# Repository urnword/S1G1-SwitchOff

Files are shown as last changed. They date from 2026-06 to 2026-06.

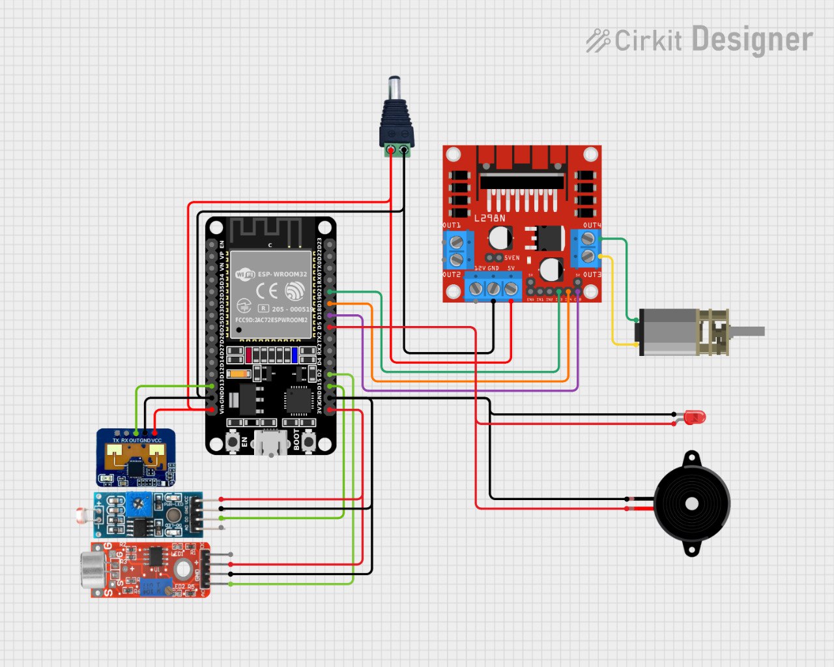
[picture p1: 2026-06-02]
hardware/circuit_diagram.jpg

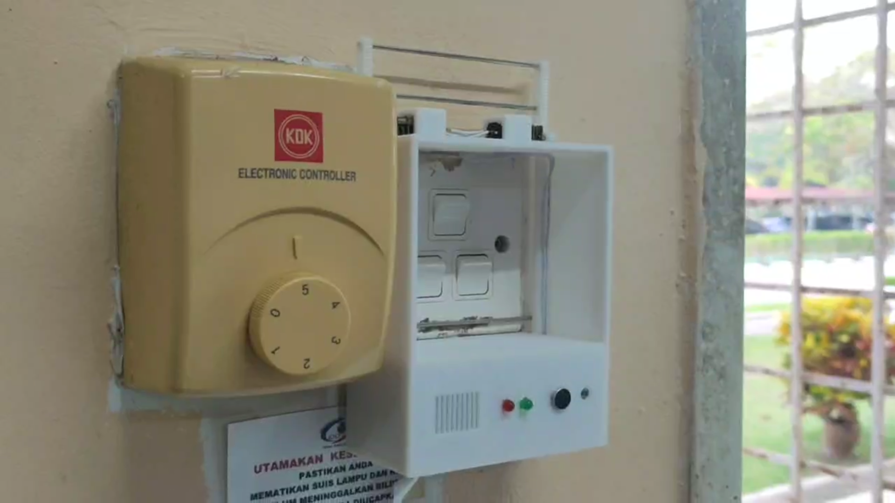
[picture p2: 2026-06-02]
docs/media/prototype.png

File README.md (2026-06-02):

# 💡 Switch Off!!!

> An IoT-powered smart switch actuator that automatically turns off lights and fans when you leave the room — controlled remotely via a web dashboard.

**CT115/CT125 Digital Technology · Semester I/II 2025/2026 · TECH CC SDN BHD**


[]()
[]()
[]()
[]()

---

## 🎯 Problem Statement

Students in dormitories routinely leave lights and fans running after leaving their rooms, leading to unnecessary energy waste, higher utility bills, and increased carbon emissions. Existing smart switch solutions require electrical rewiring — not feasible in a rented dorm environment.

## 💡 Our Solution

**Switch Off!!!** is a plug-and-play device that mounts **over** an existing wall switch without any electrical modification. It uses a motorised rack-and-pinion mechanism to physically flip the switch, controlled by an ESP32 microcontroller connected to Firebase via Wi-Fi.

Users can:
- **Monitor** room status (presence, light, fan) in real time via a web dashboard
- **Control** switches remotely from anywhere
- **Automate** switch-off when no human presence is detected for a set duration

---

## 🌐 Live Demo

👉 **[https://studio--switch-off-b68c4.us-central1.hosted.app/](https://studio--switch-off-b68c4.us-central1.hosted.app/)**

> MVP build — core monitoring and manual control features are live.

---

## 📁 Repository Structure

```
switch-off/
├── README.md                  ← You are here
├── firmware/
│   ├── README.md              ← Firmware setup & flashing guide
│   └── main.py                ← MicroPython source (ESP32)
├── hardware/
│   ├── README.md              ← Hardware assembly guide
│   ├── circuit_diagram.png    ← Wiring diagram (Cirkit Designer)
│   └── bom.md                 ← Bill of Materials
├── docs/
│   ├── README.md              ← Full project documentation
│   ├── report.pdf             ← Official project report
│   └── media/
│       ├── dashboard.png      ← Web dashboard screenshots
│       ├── prototype.jpg      ← Physical prototype photos
│       └── demo.mp4           ← Demo video
```

---

## 🔧 Hardware Overview

| Component | Role |
|---|---|
| ESP32 NodeMCU (ESP32S) | Main microcontroller — Wi-Fi, logic, motor control |
| GA12-N20 Geared Motor (3V 15RPM) | Physical switch actuation |
| L298N Mini Motor Driver | Motor direction & speed control |
| HLK-LD2410C mmWave Sensor | Human presence detection (motion + stationary) |
| GL55 LDR Sensor | Light level detection (switch ON/OFF status) |
| KY-037 Sound Sensor | Fan vibration/noise detection |
| Rack & Pinion + Metal Shaft | Converts motor rotation → linear switch movement |
| 5V 3A DC Adapter | System power supply |

> See [`hardware/README.md`](hardware/README.md) for full assembly instructions and [`hardware/bom.md`](hardware/bom.md) for sourcing details.

---

## 🖥️ Software Stack

| Layer | Technology |
|---|---|
| Firmware | MicroPython on ESP32 |
| Cloud / Database | Firebase Firestore |
| Web Dashboard | Next.js hosted on Firebase Hosting |
| 3D Enclosure Design | FreeCAD 1.0 |
| Circuit Design | Cirkit Designer |

---

## ⚡ How It Works

```
┌─────────────┐     Wi-Fi / Firestore       ┌──────────────────┐
│   ESP32     │ ◄─────────────────────────► │  Firebase Cloud  │
│             │                             └────────┬─────────┘
│  Sensors:   │                                      │ Real-time sync
│  • mmWave   │                             ┌────────▼─────────┐
│  • LDR      │                             │   Next.js Web    │
│  • Sound    │                             │   Dashboard      │
│             │                             │  (User Control)  │
│  Actuator:  │                             └──────────────────┘
│  • N20 Motor│
│  • L298N    │
└─────────────┘
       │
       ▼ Physical rack & pinion
  ┌─────────┐
  │  Wall   │
  │ Switch  │ ← flipped ON / OFF
  └─────────┘
```

**Auto-Off Logic:**
1. mmWave sensor continuously checks for human presence
2. If no presence detected + light/fan still ON → starts countdown timer
3. After delay threshold → motor activates to flip the switch OFF
4. Status synced to dashboard in real time

---

## 🚀 Getting Started

### Prerequisites
- ESP32 board (ESP32S / NodeMCU)
- MicroPython firmware flashed on the board
- Firebase project (Firestore enabled)
- Node.js 18+ (for web dashboard)

### 1. Flash the Firmware
See [`firmware/README.md`](firmware/README.md) for full flashing and configuration steps.

### 2. Configure Firebase
Update your Firestore credentials and device URL in `firmware/main.py`:
```python
WIFI_SSID = "your_wifi"
WIFI_PASS = "your_password"
DEVICE_URL = "your_firestore_device_url"
```

### 3. Run the Web Dashboard
```bash
cd web
npm install
npm run dev
```
Or deploy to Firebase Hosting — see [`docs/README.md`](docs/README.md).

---

## 📊 Test Results

| Test | Description | Result |
|---|---|---|
| TC-01 Unit | mmWave range detection (1m–5m) | ✅ Pass |
| TC-02 Unit | Sound sensor fan vs. speech isolation | ✅ Pass (after tuning) |
| TC-03 System | Environmental adaptability across rooms | ✅ Pass |
| TC-04 Integration | Data latency under rapid toggle | ✅ Pass (minor ms delay) |
| TC-05 Acceptance | Live subject real-world test ("Bilik Felo") | ✅ Pass |

Status accuracy after sensor calibration: **>90%**

---

## ⚠️ Known Limitations

- Requires constant plug-in power (no battery option yet)
- Multi-switch panels toggle all switches simultaneously (no individual control yet)
- Performance depends on Wi-Fi signal strength
- Regulator-style switches (positioned above the switch) are not currently supported

---

## 🔮 Future Work

- Support for a wider variety of switch types and configurations
- Individual switch control in multi-switch panels
- Battery / USB-C power option for portability
- User-friendly instruction manual with debugging guide
- Scheduling and energy usage analytics in the app

---

## 👥 Team — TECH CC SDN BHD

**TAIB HAZMI BIN TAIBRIZAL** • *Project Lead*

**MUHAMMAD ALTAMIS ZAFRAN BIN MOHD AFFENDY** • *Hardware Developer*

**MUHAMAD ZAID IZZUDDIN BIN NAZRI** • *Software Developer*

**NUR ERNA NADIRAH BINTI AMINUDDIN** • *System Designer*

---

## 📚 References

- Alam, M. R. et al. (2020). A review of smart homes — Past, present, and future. *Energies, 13*(15). https://doi.org/10.3390/en13154035
- Random Nerd Tutorials. ESP32 with DC motor and L298N motor driver. https://www.youtube.com/watch?v=E2sTbpFsvXI
- ESP32IO. ESP32 - Photoresistor (GL55 series) tutorial. https://esp32io.com/

---

## 📄 License

This project was developed as an academic submission for CT115/CT125 Digital Technology, Bahagian Matrikulasi, Kementerian Pendidikan Malaysia. 

© 2026 TECH CC SDN BHD. All rights reserved.

The source code and design files in this repository are provided solely for educational review and portfolio demonstration purposes. Permission is granted to view the materials, but cloning, modifying, or redistributing this work for commercial use or academic re-submission under a different name is strictly prohibited.

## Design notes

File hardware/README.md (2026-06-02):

# 🔩 Hardware — Switch Off!!!

Assembly guide, wiring reference, and Bill of Materials for the Switch Off!!! smart switch actuator.

---

## 📁 Files

```
hardware/
├── README.md           ← This file (assembly guide)
├── circuit_diagram.png ← Full wiring diagram (Cirkit Designer)
├── enclosure.stl       ← Product 3d model ensclosure
└── bom.md              ← Bill of Materials with sourcing notes
```

---

## 🧩 Bill of Materials (Quick Reference)

| # | Component | Spec | Qty |
|---|---|---|---|
| 1 | ESP32 NodeMCU (ESP32S) | 38-pin, built-in Wi-Fi/BT | 1 |
| 2 | GA12-N20 Geared DC Motor | 3V, 15RPM | 1–4 |
| 3 | L298N Mini Motor Driver | Dual H-bridge | 1 |
| 4 | HLK-LD2410C mmWave Sensor | 24GHz FMCW radar | 1 |
| 5 | GL55 LDR Module | Light-dependent resistor | 1 |
| 6 | KY-037 Sound Sensor | Microphone + comparator | 1 |
| 7 | Rack & Pinion set | Plastic, compatible with N20 shaft | 1 |
| 8 | Metal shaft | 2mm diameter | 1 |
| 9 | 5V 3A DC Power Adapter | Regulated DC | 1 |
| 10 | DC Barrel Connector (female) | 5.5mm × 2.1mm | 1 |
| 11 | LED (red + green) | 5mm, with 220Ω resistors | 2 |
| 12 | Buzzer | 5V passive/active | 1 |
| 13 | Jumper wires | M-M and M-F assorted | — |
| 14 | Custom 3D-printed enclosure | Designed in FreeCAD 1.0 | 1 |

> Full sourcing details and approximate costs: see [`bom.md`](bom.md)

---

## 📐 Circuit Overview

The ESP32 sits at the centre of the circuit:

- **Inputs:** mmWave sensor (UART), LDR (ADC), Sound sensor (ADC)
- **Outputs:** L298N motor driver → N20 motor, LED indicators, Buzzer
- **Power:** 5V 3A adapter → DC connector → L298N onboard 5V regulator → ESP32 + sensors

See `circuit_diagram.png` in this folder for the full wiring diagram.

---

## 🔌 Wiring Guide

### Power Rails
```
5V Adapter (+) ──► DC Connector (+) ──► L298N 12V pin (works with 5V)
                                    └──► ESP32 VIN
GND ─────────────────────────────────── All component GNDs (common ground)
```

### Motor Driver (L298N) → ESP32
```
L298N IN1  ──► ESP32 GPIO 26
L298N IN2  ──► ESP32 GPIO 27
L298N OUT1 ──► N20 Motor terminal A
L298N OUT2 ──► N20 Motor terminal B
```

### Sensors → ESP32
```
HLK-LD2410C TX  ──► ESP32 GPIO 16 (RX2)
HLK-LD2410C RX  ──► ESP32 GPIO 17 (TX2)
HLK-LD2410C VCC ──► 3.3V
HLK-LD2410C GND ──► GND

GL55 LDR AO  ──► ESP32 GPIO 35 (ADC)
GL55 LDR VCC ──► 3.3V
GL55 LDR GND ──► GND

KY-037 AO  ──► ESP32 GPIO 34 (ADC)
KY-037 VCC ──► 3.3V
KY-037 GND ──► GND
```

### Indicators
```
LED (Red)   (+) ──► 220Ω ──► ESP32 GPIO 22
LED (Green) (+) ──► 220Ω ──► ESP32 GPIO 23
Buzzer (+)       ──────────► ESP32 GPIO 21
All (-) ─────────────────────────────── GND
```

---

## 🏗️ Physical Assembly

### Enclosure & Mount

The enclosure is 3D-printed using FreeCAD 1.0. The design:
- Mounts **around** the existing wall switch panel using a custom bracket
- Holds the N20 motor aligned with the switch toggle
- Has cable routing channels for clean wire management
- Attaches without screws into the wall (adhesive or clip-based)

> ⚠️ **Important:** This design works with standard toggle switches. Regulator-style (rotary) switches positioned above or beside the toggle are not currently supported.

### Rack & Pinion Mechanism

```
N20 Motor shaft
      │
      ▼
  [Pinion gear]  ←──rotates──►  [Rack gear (linear)]
                                        │
                                        ▼
                                  Metal shaft (2mm)
                                        │
                                        ▼
                                  Switch toggle
                                  (physical contact)
```

Motor rotates → pinion drives rack → rack pushes shaft → shaft flips switch.

**Critical:** Motor run time must be calibrated (450–500ms) to avoid the shaft hitting the housing. See firmware `MOTOR_RUN_TIME_MS`.

---

## ✅ Assembly Checklist

- [ ] Solder all header pins on ESP32 and L298N
- [ ] Wire all sensor connections with common GND
- [ ] Test motor direction (forward = switch ON, backward = switch OFF)
- [ ] Print and fit enclosure — verify rack alignment with switch toggle
- [ ] Attach LDR module facing toward the light indicator of the switch/bulb
- [ ] Mount KY-037 sound sensor facing toward the fan (ceiling or wall-mounted)
- [ ] Connect 5V adapter and verify ESP32 boots (LED blink / serial output)
- [ ] Flash firmware and confirm Wi-Fi + Firestore connection

---

## ⚠️ Safety Notes

- This device operates at **5V DC only** — it does not connect to mains wiring
- Do not expose the circuit to moisture
- Ensure the motor bracket is firmly fixed before sustained use — mechanical stress can loosen the mount over time
- The device draws up to ~3A under motor load; use a rated 5V 3A adapter

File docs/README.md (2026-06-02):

# 📖 Documentation — Switch Off!!!

Full project documentation, architecture details, and deployment guide.

---

## 📁 Contents

```
docs/
├── README.md       ← This file
├── report.pdf      ← Official project report
└── media/
    ├── dashboard.png      ← Web dashboard screenshot
    ├── prototype.jpg      ← Physical prototype photos
    ├── circuit_diagram.png
    └── demo.mp4           ← Presentation video
```

---

## 🏗️ System Architecture

```
┌─────────────────────────────────────────────────────────────┐
│                         USER LAYER                          │
│                  Next.js Web Dashboard                      │
│         (Real-time monitoring + manual control)             │
└─────────────────────────┬───────────────────────────────────┘
                          │ HTTPS / Firestore SDK
┌─────────────────────────▼───────────────────────────────────┐
│                       CLOUD LAYER                           │
│                  Google Firebase                            │
│         Firestore (device state, commands, config)          │
│         Firebase Hosting (web app)                          │
└─────────────────────────┬───────────────────────────────────┘
                          │ HTTP REST (urequests)
┌─────────────────────────▼───────────────────────────────────┐
│                      DEVICE LAYER                           │
│              ESP32 NodeMCU (MicroPython)                    │
│                                                             │
│  Inputs:                        Outputs:                    │
│  • HLK-LD2410C (mmWave)         • L298N → N20 Motor        │
│  • GL55 LDR (light)             • LED indicators           │
│  • KY-037 Sound (fan)           • Buzzer                   │
└─────────────────────────────────────────────────────────────┘
                          │ Physical
┌─────────────────────────▼───────────────────────────────────┐
│                    PHYSICAL LAYER                           │
│         Rack & Pinion → Metal Shaft → Wall Switch          │
└─────────────────────────────────────────────────────────────┘
```

---

## 🔄 System Flowchart

### Main Loop (ESP32)

```
START
  │
  ▼
Initialize: Wi-Fi connect, sensor calibration
  │
  ▼
┌─────────────────────┐
│   READ SENSOR DATA  │ ◄────────────────────────┐
└────────┬────────────┘                           │
         │                                        │
         ▼                                        │
   HUMAN DETECTED?                                │
   YES ──► Motor OFF, keep devices on             │
   NO  ──► Check: LIGHT or FAN ON?                │
              YES ──► Start auto-off timer         │
                      Timer expired? ──► Motor ON │
              NO  ──► All good, no action          │
         │                                        │
         ▼                                        │
   CHECK CLOUD COMMANDS                           │
   (runMotor, config changes)                     │
         │                                        │
         ▼                                        │
   SEND STATUS TO FIRESTORE ─────────────────────┘
   (only on state change)
```

### Data Flow (Cloud)

```
ESP32 ──PATCH──► Firestore (status update)
                      │
                      ▼ real-time listener
              Next.js Dashboard (display)

User clicks "Turn Off"
       │
       ▼
Next.js ──WRITE──► Firestore (command: runMotor=true)
                        │
                        ▼ ESP32 polls every 200ms
                   ESP32 reads command ──► activates motor
                   ESP32 marks command executed=true
```

---

## 🌐 Web Dashboard

**Live:** [https://studio--switch-off-b68c4.us-central1.hosted.app/](https://studio--switch-off-b68c4.us-central1.hosted.app/)

### Features
- **Device overview** — list of registered Switch Off!!! devices
- **Real-time status** — Presence / Light / Fan / Switch state updated live
- **Manual control** — Turn On / Turn Off buttons send commands to the device
- **Device configuration** — Toggle Auto-Off, set delay duration
- **Last seen timestamp** — Know when the device last checked in

### Local Development

```bash
# Clone repo
git clone https://github.com/urnword/switch-off.git
cd switch-off/web

# Install dependencies
npm install

# Add your Firebase config
cp .env.example .env.local
# Fill in your Firebase project credentials in .env.local

# Run dev server
npm run dev
# Open http://localhost:3000
```

### Firebase Setup

1. Create a Firebase project at [console.firebase.google.com](https://console.firebase.google.com)
2. Enable **Firestore Database** (start in test mode for development)
3. Enable **Firebase Hosting**
4. Copy your Firebase config into `.env.local`

**Firestore Document Structure:**
```
devices/
  {deviceId}/
    fields:
      status:
        humanPresent: boolean
        fanOn: boolean
        lightOn: boolean
        motorState: "active" | "idle"
      config:
        autoOffEnabled: boolean
        autoOffDelayMs: number
        sensorSoundThreshold: number
        sensorLightThreshold: number
      command:
        runMotor: boolean
        direction: "forward" | "backward"
        executed: boolean
      lastSeen: timestamp
```

### Deploy to Firebase Hosting

```bash
npm run build
npx firebase deploy --only hosting
```

---

## 🧪 Testing Summary

We used a four-stage bottom-up testing framework:

### Stage 1 — Unit Testing
Each sensor tested in isolation before integration.
- mmWave calibrated for ideal detection distance (~1–3m for dorm rooms)
- Sound sensor frequency filter tuned to isolate fan hum from speech

### Stage 2 — System Testing
Weekly testing across multiple rooms to measure:
- Sensor accuracy under varying light conditions
- Motor reliability over repeated actuations

### Stage 3 — Integration Testing
Focus on cloud communication:
- Rapid toggle stress test (5 minutes continuous)
- Confirmed sub-second latency for control commands
- Server stability verified under high-frequency Firestore writes

### Stage 4 — Acceptance Testing
Real-world deployment in "Bilik Felo":
- Live test subject enters/exits room
- System correctly automated switch-off
- Physical mounting held firm on real wall switch

**Overall status accuracy: >90%** after sensor calibration.

---

## 🐛 Known Issues & Bugs Fixed

| Bug | Root Cause | Fix Applied |
|---|---|---|
| Motor "bangs" into housing | `delay()` too imprecise | Replaced with `MOTOR_RUN_TIME_MS` calibrated to 450–500ms |
| Fan status always "ON" | KY-037 picking up ambient noise | Added frequency-pattern filter in firmware |
| Device mounts poorly on multi-switch panels | Non-standard switch layouts | Redesigned bracket with adjustable mounting points |
| Presence false positives | mmWave too sensitive | Tuned detection sensitivity via UART configuration |

---

## 📚 Full References

- Alam, M. R., Reaz, M. B. I., & Ali, M. A. M. (2020). A review of smart homes — Past, present, and future. *Energies, 13*(15), 4035. https://doi.org/10.3390/en13154035
- Electronoobs. (2021). How to solder - 8 golden rules. https://www.youtube.com/watch?v=yKAJs2UZB6E
- ESP32IO. (n.d.). ESP32 tutorial. https://esp32io.com/
- ESP32IO. (2021). ESP32 - Photoresistor (GL55 series) tutorial. https://www.youtube.com/watch?v=5Aq_5n3zhaM
- Popular Science. (2015). Soldering basics. https://youtu.be/-THJq9LdazE
- Random Nerd Tutorials. (2019). ESP32 with DC motor and L298N motor driver. https://www.youtube.com/watch?v=E2sTbpFsvXI
- Zailani, N. F. B., & Othman, N. Z. B. (2024). *Getting started with Arduino and ESP32: A beginner's guide with Wokwi.* Politeknik Mersing. eISBN 978-967-2904-75-5

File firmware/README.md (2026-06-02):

# ⚙️ Firmware — Switch Off!!!

MicroPython firmware for the ESP32 NodeMCU that drives the Switch Off!!! smart switch actuator.

---

## 📋 Prerequisites

- ESP32 board (ESP32S / NodeMCU recommended)
- [MicroPython firmware](https://micropython.org/download/esp32/) flashed on the board
- [Thonny IDE](https://thonny.org/) **or** `mpremote` / `ampy` for uploading files
- Firebase Firestore project with a device document set up
- Wi-Fi network (2.4GHz)

---

## 📁 Files

```
firmware/
├── README.md       ← This file
└── main.py         ← Main firmware (runs automatically on boot)
```

---

## 🔌 Pin Mapping

| ESP32 GPIO | Connected To |
|---|---|
| GPIO 26 | L298N IN1 (Motor forward) |
| GPIO 27 | L298N IN2 (Motor backward) |
| GPIO 34 | KY-037 Sound Sensor (ADC) |
| GPIO 35 | GL55 LDR Sensor (ADC) |
| GPIO 16 (RX2) | HLK-LD2410C mmWave TX |
| GPIO 17 (TX2) | HLK-LD2410C mmWave RX |

> Adjust GPIO numbers in `main.py` if your wiring differs.

---

## ⚡ Setup & Flashing

### Step 1 — Flash MicroPython to the ESP32

If MicroPython is not already on your board:

```bash
# Install esptool
pip install esptool

# Erase flash
esptool.py --port COM3 erase_flash

# Flash MicroPython (replace with your .bin path and port)
esptool.py --port COM3 write_flash -z 0x1000 esp32-micropython.bin
```

> On Linux/macOS, replace `COM3` with `/dev/ttyUSB0` or similar.

### Step 2 — Configure credentials

Edit `main.py` and update the following constants at the top of the file:

```python
WIFI_SSID     = "your_wifi_name"
WIFI_PASS     = "your_wifi_password"
FIRESTORE_URL = "https://firestore.googleapis.com/v1/projects/YOUR_PROJECT/databases/(default)/documents/devices/YOUR_DEVICE_ID"
```

### Step 3 — Upload to ESP32

**Using Thonny:**
1. Open Thonny → Select interpreter: MicroPython (ESP32)
2. Open `main.py`
3. File → Save As → MicroPython device → save as `main.py`
4. Press the reset button on the ESP32

**Using mpremote:**
```bash
pip install mpremote
mpremote connect COM3 cp firmware/main.py :main.py
mpremote connect COM3 reset
```

---

## 🧠 Firmware Logic Overview

### Key Functions

| Function | Description |
|---|---|
| `start_motor(direction)` | Activates motor in `"forward"` or `"backward"` direction |
| `stop_motor()` | Stops the motor immediately |
| `check_motor_timeout()` | Auto-stops motor after calibrated run time (~450–500ms) |
| `read_radar()` | Reads human presence from HLK-LD2410C via UART |
| `fetch_device()` | Pulls config & commands from Firestore |
| `patch_device(fields)` | Pushes status updates to Firestore |
| `network_thread()` | Background thread managing Wi-Fi + cloud sync |
| `update_status(fan_on, light_on)` | Sends status to cloud only on change (efficient) |

### Auto-Off Logic

```python
if config["autoOffEnabled"]:
    if (not human_present) and (fan_on or light_on):
        if delay >= config["autoOffDelayMs"]:
            start_motor("forward")
```

The motor only runs for the calibrated `MOTOR_RUN_TIME_MS` duration, preventing it from hitting the housing (the "banging bug" fix).

---

## 🔧 Configuration (via Web Dashboard)

The following settings can be changed at runtime through the web dashboard — no reflashing needed:

| Setting | Description |
|---|---|
| `autoOffEnabled` | Enable/disable the auto-off feature |
| `autoOffDelayMs` | How long (ms) to wait after presence lost before switching off |
| `sensorSoundThreshold` | ADC threshold for detecting fan ON state |
| `sensorLightThreshold` | ADC threshold for detecting light ON state |

---

## 🐛 Troubleshooting

| Symptom | Likely Cause | Fix |
|---|---|---|
| Motor bangs into housing | `MOTOR_RUN_TIME_MS` too high | Reduce to ~450ms |
| Presence always detected | mmWave sensitivity too high | Adjust sensor sensitivity via UART config |
| Fan status incorrect | Sound threshold wrong | Increase `sensorSoundThreshold` in dashboard |
| Won't connect to Wi-Fi | Wrong credentials or 5GHz network | Ensure 2.4GHz SSID is used |
| No Firestore updates | Wrong `FIRESTORE_URL` | Double-check project ID and document path |

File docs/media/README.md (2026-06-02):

# 📸 Media — Switch Off!!!

This folder contains visual assets for the Switch Off!!! project.

## Contents

| File | Description |
|---|---|
| `dashboard.png` | Screenshot of the web dashboard (main menu + control panel) |
| `prototype.png` | Physical prototype mounted on a wall switch |
| `circuit_diagram.jpg` | Full wiring diagram exported from Cirkit Designer |
| `demo.mp4` | Short video demonstrating the full system |

## Dashboard Preview

The web interface (Next.js + Firebase) provides:
- Device list with live status summary
- Detailed control panel per device
- Real-time status: Device Online/Offline, Switch state, Light, Fan, Presence
- Manual Turn On / Turn Off controls
- Auto-Off configuration toggle

Live: [https://studio--switch-off-b68c4.us-central1.hosted.app/](https://studio--switch-off-b68c4.us-central1.hosted.app/)

## Adding Media Files

When uploading to GitHub, place files directly in this folder:
```
docs/media/
├── dashboard.png
├── prototype.jpg
├── circuit_diagram.jpg
└── demo.mp4
```

Then reference them in the main README with:
```markdown
![Dashboard](docs/media/dashboard.png)
```

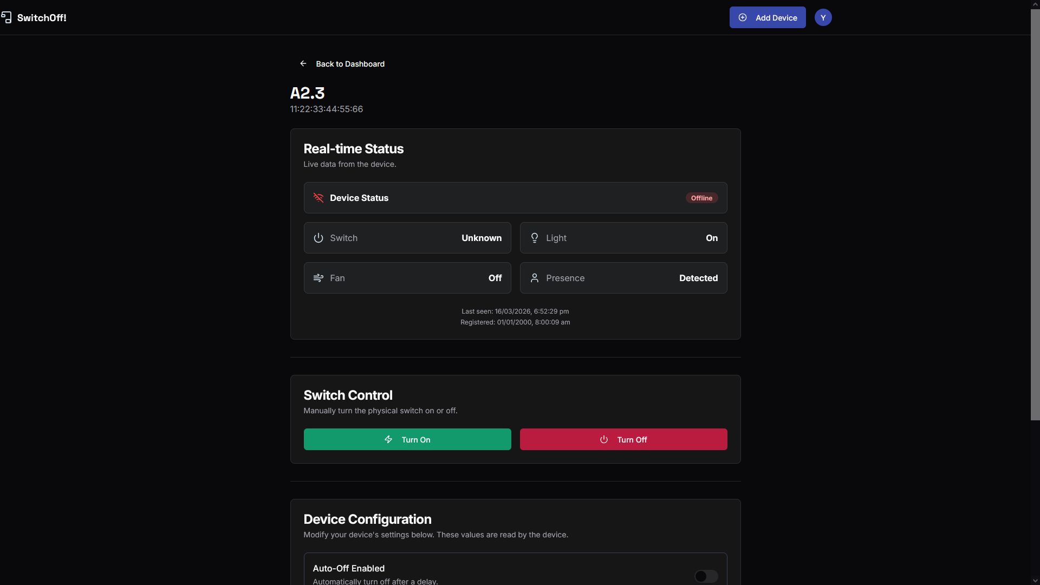
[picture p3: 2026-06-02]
docs/media/dashboard.png

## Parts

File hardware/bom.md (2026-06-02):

# 🛒 Bill of Materials — Switch Off!!!

All components used in the Switch Off!!! prototype.

> Prices are approximate and based on local Malaysian suppliers (Shopee MY / Lazada MY / component shops). As of April 2026.

---

## Hardware Components

| # | Component | Spec / Model | Est. Price (MYR) | Source |
|---|---|---|---|---|
| 1 | ESP32 NodeMCU | ESP32S, 38-pin | RM 15–20 | Shopee MY |
| 2 | GA12-N20 Geared DC Motor | 3V, 15RPM (×2 for dual switch) | RM 8–12 each | Shopee MY |
| 3 | L298N Mini Motor Driver | Mini version (not full-size) | RM 5–8 | Shopee MY / Lazada |
| 4 | HLK-LD2410C mmWave Sensor | 24GHz FMCW radar presence | RM 15–25 | Shopee MY |
| 5 | GL55 LDR Sensor Module | GL5516 or GL55 series | RM 2–4 | Shopee MY |
| 6 | KY-037 Sound Sensor | With adjustable comparator | RM 3–5 | Shopee MY |
| 7 | Rack & Pinion Gear Set | Plastic, fits 2mm N20 shaft | RM 5–10 | Shopee MY |
| 8 | Metal Shaft | 2mm diameter, ~50mm length | RM 1–3 | Hardware store |
| 9 | 5V 3A DC Power Adapter | UK plug (Malaysia standard) | RM 10–15 | Shopee MY |
| 10 | DC Barrel Connector (female) | 5.5mm × 2.1mm PCB or wire | RM 1–2 | Shopee MY |
| 11 | LED (red & green) | 5mm with 220Ω resistors | RM 1–2 | Component shop |
| 12 | Buzzer | 5V passive | RM 1–2 | Component shop |
| 13 | Jumper Wires | M-M, M-F, 20cm assorted | RM 3–5 | Shopee MY |
| 14 | 3D Print Filament (PLA) | For enclosure (~50–80g) | RM 5–10 | Printing service |

---

## Estimated Total Cost

| Tier | Cost (MYR) |
|---|---|
| Minimum (single switch unit) | ~RM 80–100 |
| Full prototype (as built) | ~RM 120–150 |

> Significantly cheaper than commercial smart switch solutions (Xiaomi, TP-Link Tapo, etc. which cost RM 60–150+ **and** require wiring modification). Switch Off!!! is non-invasive.

---

## Tools Required

| Tool | Purpose |
|---|---|
| Soldering iron + solder | Soldering headers and connections |
| Multimeter | Voltage & continuity checks |
| USB-to-microUSB cable | Flashing ESP32 |
| 3D printer or printing service | Printing the enclosure |
| Hot glue gun | Securing motor and sensors in enclosure |
| Small screwdrivers | Assembly |

---

## Software (Free / Open Source)

| Software | Purpose | License |
|---|---|---|
| MicroPython | ESP32 firmware | MIT |
| Thonny IDE | Firmware upload & debug | MIT |
| FreeCAD 1.0 | Enclosure 3D design | LGPL |
| Cirkit Designer | Circuit diagram | Free tier |
| Next.js | Web dashboard | MIT |
| Firebase | Cloud database & hosting | Free tier (Spark plan) |

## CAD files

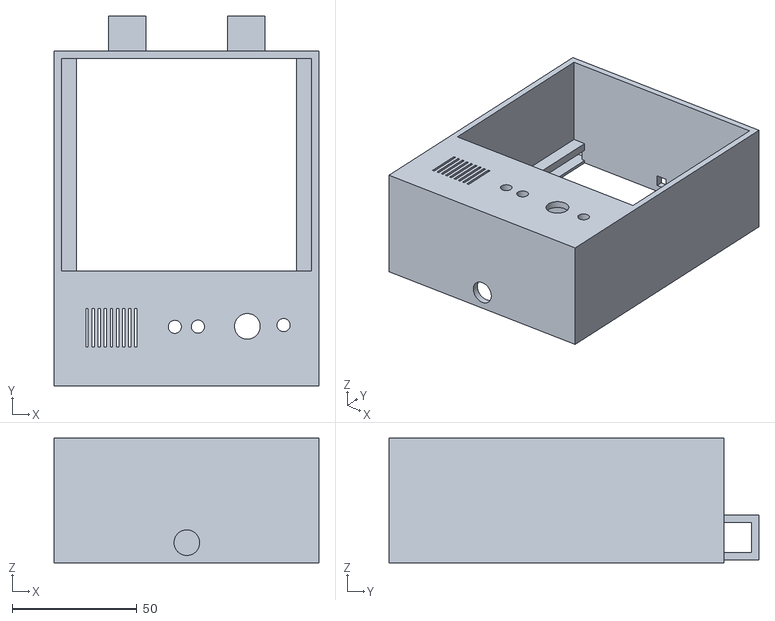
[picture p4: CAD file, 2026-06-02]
hardware/enclosure.stl
106.0 x 147.8 x 50.0

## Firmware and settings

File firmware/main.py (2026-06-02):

import machine
import time
import network
import urequests
import ujson
import utime
import ntptime
import _thread

# ================= PINS (ESP32-S) =================
RADAR_OUT_PIN = 4
KY037_A_PIN = 34
LDR_A_PIN   = 35
MOTOR_IN1 = 26
MOTOR_IN2 = 27
LED_GREEN = 18
LED_RED   = 19
BUZZER_PIN = 23

# ================= SETTINGS =================
MOTOR_RUN_TIME_MS = 9000
COMMAND_POLL_MS = 2000
WIFI_CHECK_MS = 5000
TIMEZONE_OFFSET = 8 * 3600

# ================= STATE =================
motor_active = False
human_present = False
last_status = {}
motor_start_ms = 0
last_seen_ms = 0
last_human_seen_ms = 0
auto_motor_ran_forward = False
auto_motor_ran_backward = False
firebase_connected = False
last_debug_print = 0

# ================= CONFIG =================
config = {
    "autoOffEnabled": False,
    "autoOffDelayMs": 600000,
    "sensorSoundThreshold": 2000,  # 0-4095 scale
    "sensorLightThreshold": 2000   # 0-4095 scale
}

command = {
    "runMotor": False,
    "direction": "forward",
    "executed": True
}

# ================= WIFI =================
SSID = "hotsiput"
PASSWORD = "12345678"
wifi = network.WLAN(network.STA_IF)

# ================= FIREBASE =================
PROJECT_ID = "switch-off-b68c4"
DEVICE_MAC = "11:22:33:44:55:66"
BASE_URL = f"https://firestore.googleapis.com/v1/projects/{PROJECT_ID}/databases/(default)/documents"
DEVICE_URL = f"{BASE_URL}/devices/{DEVICE_MAC}"

# ================= HARDWARE =================
motor1 = machine.Pin(MOTOR_IN1, machine.Pin.OUT)
motor2 = machine.Pin(MOTOR_IN2, machine.Pin.OUT)
led_green = machine.Pin(LED_GREEN, machine.Pin.OUT)
led_red   = machine.Pin(LED_RED, machine.Pin.OUT)
buzzer = machine.PWM(machine.Pin(BUZZER_PIN))
buzzer.duty_u16(0)
adc_sound = machine.ADC(machine.Pin(KY037_A_PIN))
adc_light = machine.ADC(machine.Pin(LDR_A_PIN))
radar = machine.Pin(RADAR_OUT_PIN, machine.Pin.IN)

# ================= WATCHDOG =================
wdt = machine.WDT(timeout=8000)

# ================= BUZZER =================
BUZZER_SOUNDS = {
    "wifi_ok":[(550,0.1),(660,0.1),(880,0.2)],
    "firebase_ok":[(880,0.3),(990,0.3)],
    "motor":[(440,0.1),(550,0.1),(660,0.1)],
    "error":[(220,0.4)]
}

def buzzer_play(name):
    if name not in BUZZER_SOUNDS:
        return
    for freq,dur in BUZZER_SOUNDS[name]:
        buzzer.freq(freq)
        buzzer.duty_u16(32768)
        time.sleep(dur)
        buzzer.duty_u16(0)
        time.sleep(0.05)

# ================= TIME =================
def sync_time():
    try:
        print("[NTP] Syncing time...")
        ntptime.settime()
        now = utime.time() + TIMEZONE_OFFSET
        tm = utime.localtime(now)
        print("[NTP] Synced: %04d-%02d-%02d %02d:%02d:%02d" %
              (tm[0],tm[1],tm[2],tm[3],tm[4],tm[5]))
        return True
    except Exception as e:
        print("[NTP] Failed:",e)
        buzzer_play("error")
        return False

def fs_now():
    t = utime.localtime(utime.time()+TIMEZONE_OFFSET)
    return {
        "timestampValue":"%04d-%02d-%02dT%02d:%02d:%02dZ" % (
            t[0],t[1],t[2],t[3],t[4],t[5]
        )
    }

# ================= HELPERS =================
def adc_avg(adc, n=5):
    s = 0
    for _ in range(n):
        s += adc.read_u16() >> 4  # convert 16-bit to 12-bit (0-4095)
        time.sleep_ms(2)
    return s // n

def read_radar():
    return radar.value()

def update_leds():
    if motor_active:
        led_red.value(1)
        led_green.value(0)
    else:
        led_red.value(0)
        led_green.value(1)

# ================= MOTOR =================
def start_motor(direction):
    global motor_active, motor_start_ms
    motor_active=True
    motor_start_ms=time.ticks_ms()
    if direction=="forward":
        motor1.value(1)
        motor2.value(0)
    else:
        motor1.value(0)
        motor2.value(1)
    update_leds()
    buzzer_play("motor")
    print("[MOTOR] start:",direction)

def stop_motor():
    global motor_active
    motor_active=False
    motor1.value(0)
    motor2.value(0)
    update_leds()
    print("[MOTOR] stopped")

def check_motor_timeout():
    if motor_active and time.ticks_diff(time.ticks_ms(), motor_start_ms)>=MOTOR_RUN_TIME_MS:
        stop_motor()

# ================= WIFI =================
def wifi_connect():
    if wifi.isconnected():
        return True
    print("[WIFI] Connecting...")
    wifi.active(True)
    wifi.connect(SSID,PASSWORD)
    start=time.ticks_ms()
    while not wifi.isconnected():
        if time.ticks_diff(time.ticks_ms(), start)>10000:
            print("[WIFI] Failed")
            buzzer_play("error")
            return False
        time.sleep(0.5)
    print("[WIFI] Connected:",wifi.ifconfig())
    sync_time()
    buzzer_play("wifi_ok")
    return True

# ================= FIRESTORE =================
def fetch_device():
    global config, command, firebase_connected
    try:
        r = urequests.get(DEVICE_URL)
        if r.status_code != 200:
            r.close()
            return False
        data = r.json()
        r.close()
        if "fields" not in data:
            return False
        fields = data["fields"]
        if not firebase_connected:
            print("[FIREBASE] Connected")
            buzzer_play("firebase_ok")
            firebase_connected = True
        if "config" in fields:
            c = fields["config"]["mapValue"]["fields"]
            config["autoOffEnabled"] = c["autoOffEnabled"]["booleanValue"]
            config["autoOffDelayMs"] = int(c["autoOffDelayMs"]["integerValue"])
            config["sensorSoundThreshold"] = int(c["sensorSoundThreshold"]["integerValue"])
            config["sensorLightThreshold"] = int(c["sensorLightThreshold"]["integerValue"])
        if "command" in fields:
            cmd = fields["command"]["mapValue"]["fields"]
            command["runMotor"] = cmd["runMotor"]["booleanValue"]
            command["direction"] = cmd["direction"]["stringValue"]
            command["executed"] = cmd["executed"]["booleanValue"]
        return True
    except Exception as e:
        print("[FIREBASE] Fetch error:",e)
        buzzer_play("error")
        return False

def patch_device(fields):
    try:
        masks = ["updateMask.fieldPaths="+k for k in fields]
        url = DEVICE_URL + "?" + "&".join(masks)
        r = urequests.patch(
            url,
            headers={"Content-Type":"application/json"},
            data=ujson.dumps({"fields":fields})
        )
        r.close()
    except Exception as e:
        print("[FIREBASE] Patch error:", e)

# ================= STATUS =================
def update_status(fan_on, light_on):
    global last_status
    current = {
        "humanPresent": human_present,
        "fanOn": fan_on,
        "lightOn": light_on,
        "motorState":"active" if motor_active else "idle"
    }
    if current != last_status:
        patch_device({
            "status": {"mapValue": {"fields": {
                "humanPresent":{"booleanValue":current["humanPresent"]},
                "fanOn":{"booleanValue":current["fanOn"]},
                "lightOn":{"booleanValue":current["lightOn"]},
                "motorState":{"stringValue":current["motorState"]},
                "updatedAt": fs_now()
            }}}
        })
        last_status = current

# ================= NETWORK THREAD =================
def network_thread():
    global last_seen_ms
    last_poll=0
    last_wifi_check=0
    while True:
        now=time.ticks_ms()
        if time.ticks_diff(now,last_wifi_check) > WIFI_CHECK_MS:
            if not wifi.isconnected():
                wifi_connect()
            last_wifi_check=now
        if wifi.isconnected() and time.ticks_diff(now,last_poll) > COMMAND_POLL_MS:
            fetch_device()
            last_poll=now
        if time.ticks_diff(now,last_seen_ms) > 60000:
            patch_device({"lastSeen": fs_now()})
            last_seen_ms=now
        time.sleep_ms(200)

# ================= STARTUP =================
wifi_connect()
last_human_seen_ms=time.ticks_ms()
_thread.start_new_thread(network_thread, ())
print("[SYSTEM] Ready")

# ================= MAIN LOOP =================
while True:
    wdt.feed()
    now=time.ticks_ms()
    human_present=read_radar()
    sound_val=adc_avg(adc_sound)
    light_val=adc_avg(adc_light)
    fan_on = sound_val > config["sensorSoundThreshold"]
    light_on = light_val > config["sensorLightThreshold"]

    if human_present:
        last_human_seen_ms=now
        auto_motor_ran_forward=False

    if config["autoOffEnabled"]:
        delay = time.ticks_diff(now, last_human_seen_ms)
        if (not human_present) and (fan_on or light_on) and delay >= config["autoOffDelayMs"]:
            if not motor_active and not auto_motor_ran_forward:
                start_motor("forward")
                auto_motor_ran_forward=True
                auto_motor_ran_backward=False

    if command["runMotor"] and not command["executed"] and not motor_active:
        start_motor(command["direction"])
        patch_device({
            "command":{"mapValue":{"fields":{
                "runMotor":{"booleanValue":False},
                "direction":{"stringValue":command["direction"]},
                "executed":{"booleanValue":True}
            }}}
        })

    check_motor_timeout()
    update_leds()
    update_status(fan_on, light_on)

    # ================= LIVE SENSOR DEBUG =================
    print("\rRadar:{} Sound:{} Light:{} Motor:{} WiFi:{} Firebase:{}"\
          .format(human_present, sound_val, light_val, motor_active, wifi.isconnected(), firebase_connected), end='')

    time.sleep_ms(200)
